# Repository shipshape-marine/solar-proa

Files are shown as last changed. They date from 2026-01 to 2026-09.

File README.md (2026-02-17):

# Solar Proa

## About

The solar proa is a novel boat design for carbon-neutral
small-scale tropical maritime transport, exploration, and tourism.
These boats combine traditional Southeast Asian and Polynesian
boat designs and rigs with solar power and modern materials.
More on solar proas is available at the website
[https://solarproa.org](https://solarproa.org).

This repo generates the website, including the parametric boat designs
and validation.

## How this repo works

The boat models specified in this repo are available at
[https://solarproa.org](https://solarproa.org). Changes in the boat
specs here are automatically reflected in the website.

The boat designs are programmed in Python.
Design-specific components live in `src/` while boat-independent analysis is provided by the [shipshape](https://github.com/shipshape-marine/shipshape) library. Features include:
- Main macro: The boat designs are generated by the _Solar Proa Design Generator_, [`SolarProa.FCMacro`](https://github.com/shipshape-marine/solar-proa/blob/main/SolarProa.FCMacro) using [FreeCAD](https://www.freecad.org/).
- Parameters: The boat is fully parameterized; the files [`constant/boat/rp*.json`](https://github.com/shipshape-marine/solar-proa/tree/main/constant/boat/) let you choose the numbers of solar panels and the size of all components. SolarProa-specific derived parameters are computed by [`src/parameter/compute.py`](https://github.com/shipshape-marine/solar-proa/blob/main/src/parameter/compute.py), loaded as a plugin by `shipshape.parameter`.
- Configurations: Moving parts such as rig, sails, rudders etc can be configured in the files [`constant/configuration/*.json`](https://github.com/shipshape-marine/solar-proa/tree/main/constant/configuration), for example [`closehaul.json`](https://github.com/shipshape-marine/solar-proa/blob/main/constant/configuration/closehaul.json).
- Mirroring: Solar proas have a transversal symmetry axis. Most components are described in file [`mirror.py`](https://github.com/shipshape-marine/solar-proa/blob/main/src/design/mirror.py) and automatically mirrored in the generated model.
- Rotation: Some parts such as the rigs and rudder can be rotated or moved independently (see file [`rotation.py`](https://github.com/shipshape-marine/solar-proa/blob/main/src/design/rotation.py)) in the configuration files.
- Structural validation: The structural validation lives in [`src/structural/`](https://github.com/shipshape-marine/solar-proa/tree/main/src/structural) and covers aka, mast, spine, and capsize analysis.
- Validation: The validation of the designs with respect to their mechanical, electrical and naval-engineering integrity is automated and the website reflects the validation results of the latest designs.

### Repo structure

```
src/
  parameter/compute.py   SolarProa-specific derived parameter calculations
  design/                FreeCAD geometry generation (central, mirror, rotation)
  color/                 Apply colors to FreeCAD models
  render/                Render images from FreeCAD
  step/                  Export to STEP format
  lines/                 Generate lines plan drawings
  buoyancy_design/       Position the boat at equilibrium in FreeCAD
  structural/            Structural validation (aka, mast, spine, capsize)
constant/
  boat/                  Boat specifications (rp2.json, rp4.json, ...)
  configuration/         Sail/rudder configurations (closehaul.json, ...)
  material/              Material properties
```

Analysis is provided by [shipshape](https://github.com/shipshape-marine/shipshape): parameter computation, mass analysis, buoyancy equilibrium, and GZ curves.

## Getting Started

0. Install `git` and `make`:
- **Linux**: `sudo apt install git make` (Ubuntu/Debian) or `sudo dnf install git make` (Fedora/RHEL)
- **macOS**: [Install Git](https://git-scm.com/install/mac), then run `xcode-select --install` for `make`
- **Windows**: [Git for Windows](https://git-scm.com/download/win) (includes Git Bash with `make`)

1. Clone this repository with `git clone git@github.com:shipshape-marine/solar-proa.git`

2. Install [FreeCAD](https://www.freecad.org/)

3. Start FreeCAD

4. Macro > Macros, then choose the file `SolarProa.FCMacro`

5. In the Solar Proa Design Generator, choose the boat (e.g. RP2) and configuration (e.g. Closehaul).

6. You should see the design (e.g. `rp2.closehaul.design`) in the FreeCAD view.

## Playing with the FreeCAD models

Change the boat specifications and rerun the macro:
- Change `constant/boat/rp2.json` to play with the number of solar panels, length of the boat etc.
- Change `constant/configuration/closehaul.json` to play with the sail settings, rudder position etc.
- Add or change boat features by editing `src/design/central.py`, `src/design/mirror.py`, or `src/design/rotation.py` and rerun the macro.

## Generating `FCStd` and `step` files from command line

To generate all designs (all boats with all configurations) just type
```
make
```
To generate an individual design, type
```
make design BOAT=rp2 CONFIG=closehaul
```
or
```
make step BOAT=rp2 CONFIG=closehaul
```
The generated files are placed in the folder `artifact`, for example:
```
artifact/rp2.closehaul.design.FCStd
artifact/rp2.closehaul.step.step
```

## Continuous Integration/Continuous Deployment (CICD)

The issue: when we have an idea for an improvement of the design, we
would need to redo all changes in all affected artifacts: the designs,
renderings, validations, and websites. CICD takes care of that by
automatically regenerating the artifacts. This is done locally, using
the `make` facility and on the github server using a workflow. The
workflow makes sure that the [solarproa.org](https://solarproa.org)
website has always the latest versions.

## Under the hood

Crucial for the CICD approach to CAD using FreeCAD is:
- FreeCAD's [macros](https://wiki.freecad.org/Macros) feature
- the ability to run FreeCAD headlessly (with GUI), using `freecadcmd` on Linux and using `--console` on Mac
- this [observation](https://forum.freecad.org/viewtopic.php?p=857226#p857226) by FreeCAD user [`jcsahnwaldt`](https://forum.freecad.org/memberlist.php?mode=viewprofile&u=85580&sid=a9af5bd37412a3771f25378b4c027a2c) to use GUI features in headless FreeCAD with `PySide.QtGui`

Some design decisions:
- Toolchain automation with [`make`](<https://en.wikipedia.org/wiki/Make_(software)>) using this [Makefile](https://github.com/shipshape-marine/solar-proa/blob/main/Makefile)
- Website generation using [Jekyll](<https://en.wikipedia.org/wiki/Jekyll_(software)>)
- JSON statistics generated by headless FreeCAD
- Rendering by headless FreeCAD using [`jcsahnwaldt`](https://github.com/jcsahnwaldt)'s observation

## Further development

Let's explore what output formats we can generate and what tools are available to get the most out of our FreeCAD designs. Any contributions are welcome.

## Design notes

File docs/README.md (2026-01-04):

# Install dependencies
bundle install

# Run Jekyll locally
bundle exec jekyll serve

# Open in browser
open http://localhost:4000/CAD/

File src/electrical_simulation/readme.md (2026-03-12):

# Installing PySpice and NgSpice for electonic circuit simulation

```bash
pip install pyspice

pyspice-post-installation --install-ngspice-dll

pyspice-post-installation --check-install
```

## Note:

Spice identifier name should not start with number or 'v'

- Number used to indicate array index for MPPT and solar panels
- v prefix added by ngspice removed for result output

<br>

# Intepreting Simulation Results

Decoding of s & p can be found using the regex key in [this file](../../constant/electrical/constants.json)

## Errors 

```json
    "error": {
        "keyword": "error",
        "array_count": 2,
        "data": [
            "(Array 0) Panel input current (18.2 A) exceeds max MPPT input current (5.0 A)",
            "(Array 1) Panel input current (18.2 A) exceeds max MPPT input current (5.0 A)"
        ]
    },
```

Errors are important issues that must be fixed before deploying the vessel. These errors if not fixed, is a hazzard in regards to fire and electrical safety.

## Warnings

```json
    "warning": {
        "keyword": "warning",
        "array_count": 1,
        "data": [
            "Battery array is being over-discharged. Motor 0 has been restricted to 129.04% instead of 1000.00% throttle level."
        ]
    },
```

Warnings are restrictions on the components due to limitations (i.e. Max battery discharge rate). They may cause issues such as pre-mature shutdown of the components as a safety features by the manufacturer. This is not an indicator that the vessel is unsafe but a simple warning that the components will not run as expected.

## Quick Summary 

```json
    "summary": {
        "keyword": "total",
        "array_count": 1,
        "data": [
            {
                "array_index": 0,
                "voltage": {
                    "total_mppt_output": 58.18912913606731,
                    "total_dc_bus_voltage": 58.18912813606731
                },
                "current": {
                    "total_mppt_output_current": 37.48509485,
                    "total_battery_input_current": -30.542116090829495
                }
            }
        ]
    },
```

A general overview of the system's status.

## MPPT (Array)

```json
    "mppt_result": {
        "keyword": "mppt",
        "array_count": 2,
        "data": [
            {
                "array_index": 0,
                "voltage": {
                    "mppt_output": 58.376555610317304
                },
                "current": {
                    "mppt_output": 18.742547425
                }
            },
            {
                "array_index": 1,
                "voltage": {
                    "mppt_output": 58.376555610317304
                },
                "current": {
                    "mppt_output": 18.742547425
                }
            }
        ]
    },
```

Depending on how many MPPT-Solar arrays are configured. RP2 will have 2 of it. Naming is from PySpice netlist but since MPPTs should not connect in series in any configurations due to safety issue, there will only ever be one voltage and current reading per array.

## Batteries
```json
    "battery_result": {
        "keyword": "battery",
        "array_count": 1,
        "data": [
            {
                "array_index": 0,
                "voltage": {
                    "p0_s1_battery_negative": 29.094548296975614,
                    "p0_s1_battery_positive": 58.494548296975616,
                    "p0_s0_battery_negative": -3.054211609082995e-05,
                    "p0_s0_battery_positive": 29.399969457883913
                },
                "current": {
                    "p0_s0_battery": -30.54211609082995,
                    "p0_s1_battery": -30.54211609082995
                }
            }
        ]
    },
```

Batteries only has 1 array count, but can be configured into series and parallel connection (Indicated by p & s). Can be decoded using the above regex key. Positive current: charging, Negative current: discharging.

## Solar Panel (Array)

```json
    "solar_result": {
        "keyword": "solar_array",
        "array_count": 2,
        "data": [
            {
                "array_index": 0,
                "voltage": {
                    "solar_array_output": 79.95455269744532
                },
                "current": {
                    "solar_array_output": 18.18966051116881
                }
            },
            {
                "array_index": 1,
                "voltage": {
                    "solar_array_output": 80.045449302557
                },
                "current": {
                    "solar_array_output": 18.210339488831718
                }
            }
        ]
    },
```

Following the MPPT_Solar array setup, each array corresponds to the array before. This section will be the input into their respective MPPT.

## Individual Solar Panels

```json
    "panel_result": {
        "keyword": "panel",
        "array_count": 2,
        "data": [
            {
                "array_index": 0,
                "voltage": {
                    "p1_s0_panel_positive": -9.100000000000001e-06,
                    "p1_1_panel_positive": 80.04550100000117,
                    "p1_1_panel_negative": -9.1e-06,
                    "p1_0_panel_positive": 9.1,
                    "p1_0_panel_negative": -9.1e-06,
                    "p0_s0_panel_positive": -9.100000000000001e-06,
                    "p0_1_panel_positive": 80.04550100000117,
                    "p0_1_panel_negative": -9.1e-06,
                    "p0_0_panel_positive": 9.1,
                    "p0_0_panel_negative": -9.1e-06
                },
                "current": {}
            },
            {
                "array_index": 1,
                "voltage": {
                    "p1_s0_panel_positive": -9.100000000000001e-06,
                    "p1_1_panel_positive": 80.136449302557,
                    "p1_1_panel_negative": -9.1e-06,
                    "p1_0_panel_positive": 9.1,
                    "p1_0_panel_negative": -9.1e-06,
                    "p0_s0_panel_positive": -9.100000000000001e-06,
                    "p0_1_panel_positive": 80.136449302557,
                    "p0_1_panel_negative": -9.1e-06,
                    "p0_0_panel_positive": 9.1,
                    "p0_0_panel_negative": -9.1e-06
                },
                "current": {}
            }
        ]
    },
```

Not a big concern. Factory cable is more than sufficient to carry the short connections between panels of up to 10 - 15A (10 - 12 AWG cables is more than sufficient).

## Load Balancer (Virtual)

```json
    "load_balancer": {
        "keyword": "balancing_load",
        "array_count": 1,
        "data": [
            {
                "array_index": 0,
                "voltage": {
                    "balancing_load": 58.18912713606731
                },
                "current": {
                    "balancing_load": 0.0
                }
            }
        ]
    },
```

Battery discharge limiter. Acts as a clamp to limit the battery to its specified discharge rate. Not a physical component.

## Loads

```json
    "load_result": {
        "keyword": "load",
        "array_count": 2,
        "data": [
            {
                "array_index": 0,
                "voltage": {
                    "load_torqeedo_cruise_4.0_positive": 56.8278085909551
                },
                "current": {
                    "load_torqeedo_cruise_4.0": 9.728971153497696
                },
                "motor_physics": {
                    "model_type": "BLDC",
                    "speed_rpm": 3245.7,
                    "efficiency": 0.89,
                    "power_mechanical_w": 1520.3,
                    "power_electrical_w": 1708.2,
                    "torque_nm": 4.47,
                    "is_stalled": false,
                    "propeller_load_factor": 1.0
                }
            },
            {
                "array_index": 1,
                "voltage": {
                    "load_torqeedo_cruise_6.0_positive": 56.147536482138094
                },
                "current": {
                    "load_torqeedo_cruise_6.0": 77.75618203729391
                },
                "motor_physics": {
                    "model_type": "linear",
                    "speed_rpm": null,
                    "efficiency": null,
                    "power_mechanical_w": null,
                    "power_electrical_w": 4365.2,
                    "torque_nm": null,
                    "is_stalled": null
                }
            }
        ]
    },
```

Loads are no longer stored within a single array (Similar to panels). Each load is its own index in the array. 

### Motor Physics Model (New)

When motor physics constants are configured in `components.json`, the simulation uses a BLDC motor model with optional propeller load coupling instead of the linear throttle-to-power conversion.

**Motor model features:**
- **Back-EMF**: Speed-dependent voltage that opposes motor current
- **Propeller equilibrium**: Finds operating point where motor torque = propeller torque (τ = Kp × ω²)
- **ESC current limiting**: Caps winding current at rated current (`total_power / nominal_voltage`)
- **Auto-derived propeller kp**: Calibrated so motor reaches rated current at full throttle
- **Efficiency calculation**: Mechanical power / electrical power
- **Non-linear power scaling**: Power scales with ~throttle³ due to propeller load curve

**Configuration** (in `constant/electrical/components.json`):

```json
"Torqeedo_Cruise_2.0": {
    "total_power": 2000,
    "nominal_voltage": 24.0,
    "motor_kv": 150,           // Motor velocity constant (RPM/V)
    "motor_resistance": 0.05,   // Winding resistance (ohms)
    "motor_no_load_current": 1.5, // No-load current (amps)
    "propeller_load_factor": 1.0  // 1.0=startup/bollard, 0.3-0.6=cruise equilibrium
}
```

The propeller load coefficient (`kp`) is auto-derived from motor specs so that the motor reaches its rated current at full throttle. To override with a custom value, add `"propeller_kp": <value>` to the config.

**ESC Current Limiting:**

The model simulates ESC current limiting: `max_current = total_power / nominal_voltage`. When the motor would exceed this, the ESC reduces voltage to hold the limit. Key behaviors when current-limited:
- Motor torque is constant (capped by current limit)
- Equilibrium speed is fixed regardless of throttle
- Power draw plateaus — increasing throttle has no further effect
- The `is_current_limited` output field indicates this condition

**Propeller Load Factor:**

The `propeller_load_factor` parameter (0.0–1.0, default 1.0) scales the propeller load coefficient `propeller_kp` to simulate different operating conditions:

| Value | Condition | Description |
|---|---|---|
| 1.0 | Startup / bollard pull | Boat stationary, propeller pushes against still water. Maximum power draw. |
| 0.5 | Moderate cruise | Water flowing through propeller reduces effective load by ~50%. |
| 0.3 | High-speed cruise | Propeller advancing rapidly, low slip, minimal loading. |
| 0.0 | Free-spinning | No propeller load (theoretical boundary). |

At startup (load_factor=1.0), power draw is **higher** than at cruise equilibrium because the propeller faces maximum water resistance. As the boat accelerates and water flows into the propeller, the effective load decreases.

You can estimate the factor from manufacturer power-at-speed data: if the motor draws 4kW at bollard pull but only 1.5kW at cruise speed, use `propeller_load_factor ≈ 0.375`.

The parameter can be overridden at runtime via `--propeller-load-factor` CLI argument, or set per-segment in voyage configurations.

**Backward compatibility:** If motor physics constants are not provided, the simulation falls back to the original linear model where `power = throttle × total_power`.

**Motor physics output fields:**
- `model_type`: "BLDC" for physics model, "linear" for fallback
- `speed_rpm`: Motor speed in RPM (null for linear model)
- `efficiency`: Motor efficiency 0-1 (null for linear model)
- `power_mechanical_w`: Mechanical power output (null for linear model)
- `power_electrical_w`: Electrical power consumption
- `torque_nm`: Motor torque in N·m (null for linear model)
- `is_stalled`: True if motor is in stall condition
- `is_current_limited`: True if ESC is limiting winding current
- `propeller_load_factor`: Load factor used (1.0=startup, <1.0=cruise)

Note: Due to limitations in PySpice simulation of a current limiter, if > 1 load is connected and in total is drawing > 200% of the bus output, the current of the motor may be negative (Indicating the load is a power source).

## Load (Array)

```json
    "l_array_result": {
        "keyword": "l_array",
        "array_count": 1,
        "data": [
            {
                "array_index": 0,
                "voltage": {
                    "l_array_positive": 57.508856026659025
                },
                "current": {}
            }
        ]
    }
```

New: placeholder section for the implemented load array.

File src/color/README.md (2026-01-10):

# Color Module

The color module applies material-based color schemes to FreeCAD designs. Colors, transparency, and display modes are defined in JSON files and applied based on material annotations in object labels.

## Overview

**Pipeline**: `design.FCStd` → `color module` → `color.FCStd` → `render module` → `PNG images`

The color module is a separate processing step that:
1. Reads a color scheme from JSON
2. Applies colors, transparency, and display modes to objects based on their materials
3. Saves a colored version of the design (`.color.FCStd`)
4. Generates a JSON artifact with statistics

## Usage

### Apply Colors to a Design

```bash
# Apply default color scheme
make color BOAT=rp2 CONFIGURATION=closehaul

# Apply specific color scheme
make color BOAT=rp2 CONFIGURATION=closehaul COLOR_SCHEME=wiring_view

# Apply colors to all existing designs
make color-all

# Apply specific scheme to all designs
make color-all COLOR_SCHEME=proa
```

### Generated Files

For `rp2.closehaul` with `proa` color scheme:
- `artifacts/rp2.closehaul.color.FCStd` - Colored FreeCAD design
- `artifacts/rp2.closehaul.color.json` - Statistics artifact

## Color Scheme Format

Color schemes are defined in `constants/colors/*.json`:

```json
{
  "scheme_name": "Proa Standard Colors",
  "description": "Default color scheme for solar proa visualizations",
  "version": "1.0",
  "materials": {
    "aluminum": {
      "color": [0.75, 0.75, 0.78],
      "transparency": 0,
      "display_mode": "Shaded",
      "description": "Structural aluminum tubes and profiles"
    },
    "plywood": {
      "color": [0.76, 0.60, 0.42],
      "transparency": 0,
      "display_mode": "Shaded",
      "description": "Marine plywood decking and structure"
    }
  }
}
```

### Color Scheme Properties

- **color**: RGB values from 0.0 to 1.0
- **transparency**: Integer from 0 (opaque) to 100 (fully transparent)
- **display_mode**: FreeCAD display mode (e.g., "Shaded", "Wireframe", "Flat Lines")

## Material Detection

The color module extracts material names from object labels using two formats:

### Format 1: Parentheses (legacy)
```
"Aka_0 (aluminum)" → material: "aluminum"
"Stanchion_2 (steel)" → material: "steel"
```

### Format 2: Double Underscore (preferred)
```
"Deck__plywood_001" → material: "plywood"
"Hull__marine_plywood" → material: "marine_plywood"
```

Both formats are case-insensitive and trailing numbers are stripped.

## Available Color Schemes

### `proa.json` (Default)
Standard color scheme for regular visualization. All materials opaque, realistic colors.

### `wiring_view.json` (Specialized)
Transparent hull view for showing electrical systems:
- Structure (aluminum, plywood): 80% transparent
- Hull exterior: 90% transparent
- Electrical components (wires, batteries, solar panels): Opaque with high-contrast colors

## Creating Custom Color Schemes

1. Create a new JSON file in `constants/colors/`
2. Define materials used in your designs
3. Set appropriate color, transparency, and display mode
4. Use it: `make color COLOR_SCHEME=your_scheme`

### Example: High Contrast Scheme

```json
{
  "scheme_name": "High Contrast",
  "description": "High contrast colors for presentations",
  "version": "1.0",
  "materials": {
    "aluminum": {
      "color": [0.2, 0.2, 0.8],
      "transparency": 0,
      "display_mode": "Shaded"
    },
    "plywood": {
      "color": [0.8, 0.5, 0.1],
      "transparency": 0,
      "display_mode": "Shaded"
    }
  }
}
```

## Platform Differences

### Linux
- Uses `freecad-python` in headless mode
- Colors applied via `color.py` script
- Fast and reliable

### macOS
- Requires GUI mode to persist ViewObject properties
- Uses `color_mac.sh` wrapper script
- Opens FreeCAD, applies colors, saves, quits
- Takes longer but produces identical results

## Integration with Build Pipeline

The color module is integrated into the Makefile dependency chain:

```
parameters.json
    ↓
design.FCStd
    ↓
color.FCStd  ← color scheme JSON
    ↓
render PNGs
```

Renders automatically depend on colored designs. If you run `make render`, it will:
1. Generate parameters (if needed)
2. Generate design (if needed)
3. Apply colors (if needed)
4. Render images

## Statistics Artifact

The `.color.json` artifact contains:

```json
{
  "validator": "color",
  "input_design": "artifacts/rp2.closehaul.design.FCStd",
  "output_design": "artifacts/rp2.closehaul.color.FCStd",
  "color_scheme_file": "constants/colors/proa.json",
  "color_scheme_name": "Proa Standard Colors",
  "statistics": {
    "total_objects": 150,
    "colored_objects": 142,
    "by_material": {
      "aluminum": 45,
      "plywood": 38,
      "steel": 29,
      "solar_panel": 18,
      "canvas": 12
    }
  }
}
```

## Troubleshooting

### No colors appear in renders

Check:
1. Does the object label include material? (e.g., "Aka_0 (aluminum)")
2. Is the material defined in the color scheme JSON?
3. Does the colored FCStd exist? (`artifacts/*.color.FCStd`)
4. Are you rendering the `.color.FCStd` file (not `.design.FCStd`)?

### Some objects not colored

Check the statistics in the `.color.json` artifact to see which materials were found and colored. Objects without material annotations or with undefined materials won't be colored.

### macOS color application hangs

The `color_mac.sh` script has a 30-second timeout. If it hangs:
1. Check if FreeCAD is installed at the expected path
2. Try running FreeCAD manually to verify it works
3. Check for FreeCAD processes that didn't exit cleanly

## Future Enhancements

Potential future features:
- Material-specific transparency for "exploded" views
- Animation support for rotating/transparency transitions
- Color validation (warn if materials in design aren't in scheme)
- Color scheme inheritance (extend base schemes)
- Per-object color overrides for special highlighting

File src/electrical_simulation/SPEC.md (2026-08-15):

# Electrical Simulation Module (`src/electrical_simulation`)

## Purpose

SPICE-based electrical circuit simulation of the solar proa's power system. Models solar panels, MPPT charge controllers, batteries, and electric motor loads to analyse power flow, validate component sizing, and simulate voyage energy profiles.

## Status: Active Development

Core simulation pipeline is functional. See `todo.md` for planned fixes.

---

## Architecture

```
__main__.py              CLI entry point & orchestrator
├── circuit_constructor  Builds PySpice netlist from JSON config
├── pyspice_simulator    Executes NgSpice operating point analysis
├── parse_result         Extracts node voltages/branch currents → structured dict
├── result_checker       Validates results (Kirchhoff, component limits, motor physics)
├── result_saver         Serialises results to JSON
├── simulation_sweeper   Runs parameter sweeps (throttle, panel power)
├── simulation_over_time Multi-segment voyage simulation with SOC tracking
├── sweep_graph_generation Matplotlib graph output (PNG)
├── cable_sizing         Derives cable gauge from max-current simulation
└── components/
    ├── solar_panel_array  Solar panel PySpice model (series/parallel)
    ├── mppt               MPPT charge controller model
    ├── battery_array      Battery bank model (series/parallel, SOC)
    ├── load               Individual load with BLDC motor physics
    ├── load_array         Multi-load bus connection & current distribution
    ├── load_balancer      Virtual battery discharge limiter
    └── motor_model        BLDC motor physics (back-EMF, propeller coupling)
```

---

## Dependencies (Centralised Parameters)

All parameters are loaded at runtime from JSON — no hardcoded values.

| File | Purpose | Key Fields |
|---|---|---|
| `constant/electrical/{boat}_circuit_setup.json` | Circuit topology per boat | `mppt_panel` (arrays, count, panel/MPPT choice), `load` (choice, throttle), `battery` (choice, series, parallel, SOC) |
| `constant/electrical/electrical_components.json` | Component specifications | `MPPT` (voltage/current limits, efficiency), `Panel` (power, voltage), `Battery` (voltage, capacity, charge/discharge limits), `Load` (power, voltage, motor physics) |
| `constant/electrical/constants.json` | Simulation constants | `GROUNDING_RESISTANCE`, `WIRE_RESISTANCE`, `EPSILON`, `ARRAY_DECODER_PATTERN`, tolerance values |
| `constant/electrical/voyage_setup.json` | Voyage segments | `segments[]` (duration_minutes, throttle, solar_power, propeller_load_factor) |
| `constant/boat/{boat}.json` | Boat physical params | `panels_longitudinal`, `panels_transversal`, `panels_per_string` → derived `in_series`, `in_parallel` for panel arrays |

### Dependency Graph

```
constant/boat/{boat}.json ──────────────────┐
constant/electrical/{boat}_circuit_setup.json ├──→ circuit_constructor → pyspice_simulator
constant/electrical/electrical_components.json ┘           │
constant/electrical/constants.json ─────────────────────── ┤
constant/electrical/voyage_setup.json ──────────── simulation_over_time
```

---

## CLI Usage

```bash
python -m src.electrical_simulation \
  --circuit constant/electrical/rp2_circuit_setup.json \
  --constants constant/electrical/constants.json \
  --components constant/electrical/electrical_components.json \
  --boat rp2 \
  --boat-params constant/boat/rp2.json \
  --voyage constant/electrical/voyage_setup.json \
  --output artifact/rp2.electrical_simulation \
  --simulation-type all
```

### Simulation Types

| Type | Description | Output |
|---|---|---|
| `operating_point` | Single DC steady-state | `.operating_point.json` |
| `cable_sizing` | Max-current operating point for cable gauge | `.max_operating_point.json` |
| `sweep_throttle` | 0→100% throttle sweep (101 points) | `.sweep_throttle.*.png`, `.json` |
| `sweep_panel_power` | 100→1% panel power sweep (100 points) | `.sweep_panel_power.*.png`, `.json` |
| `voyage` | Multi-segment time simulation | `.voyage.*.png` |
| `all` | Run all of the above sequentially | All outputs |

### Makefile Integration

```makefile
make electrical-simulation BOAT=rp2 SIMULATION_TYPE=all
```

---

## Result Structure

Results are a nested dictionary with these top-level keys:

```
info            → metadata (name, date)
error           → critical violations (Kirchhoff's law, component limits)
warning         → operational restrictions (discharge limiting, ESC capping)
summary         → total MPPT output voltage/current, DC bus voltage
mppt_result     → per-array MPPT output voltage/current
battery_result  → per-cell voltage, charge/discharge current
solar_result    → per-array solar output voltage/current
panel_result    → per-panel voltage (usually not critical)
load_balancer   → virtual balancer voltage/current
load_result     → per-load voltage/current + motor_physics
l_array_result  → load array bus voltage
```

Each section follows: `{ keyword, array_count, data: [{ array_index, voltage: {}, current: {} }] }`

---

## Key Algorithms

### Motor Physics (BLDC Model)

When `motor_kv`, `motor_resistance` are specified in component config:
1. Compute back-EMF constant: `Ke = 1 / (motor_kv * 2π/60)`
2. Auto-derive propeller Kp so motor reaches rated current at full throttle
3. Solve propeller-motor equilibrium: motor torque = Kp_effective × ω²
4. ESC current limiting: cap winding current at `total_power / nominal_voltage`
5. Output: speed_rpm, efficiency, torque, power_mechanical, is_stalled, is_current_limited

Falls back to linear model (`power = throttle × total_power`) when physics constants absent.

### Voyage SOC Tracking

1. Simulate each segment at 1-minute intervals
2. Integrate battery current: `capacity += current × step_time`
3. Boundary handling: split time step at exact SOC=0 or SOC=1 boundary
4. Re-simulate with discharge/charge disabled for remaining interval

---

## Unit Testing Guidance

### Critical Invariants to Test

1. **Kirchhoff's Current Law**: `Σ MPPT_out - Σ battery_in - Σ load_current = 0` (within EPSILON)
2. **Power conservation**: Input solar power × efficiency ≈ output power + losses
3. **SOC bounds**: `0.0 ≤ SOC ≤ 1.0` at all voyage time steps
4. **Motor physics**: speed, torque, efficiency within physical bounds
5. **Current limiting**: load current ≤ battery max_discharge_current

### Suggested Test Structure

```
tests/
├── test_circuit_constructor.py    # Config loading, component resolution
├── test_motor_model.py            # BLDC equilibrium, current limiting, edge cases
├── test_result_checker.py         # Kirchhoff validation, warning generation
├── test_simulation_sweeper.py     # Sweep produces expected point count
├── test_voyage.py                 # SOC boundary splitting, segment transitions
└── test_cable_sizing.py           # Current → gauge mapping
```

### Test Fixtures

- Use `constant/electrical/rp2_circuit_setup.json` as reference config
- Mock NgSpice for unit tests (test circuit_constructor independently)
- Use known-good result JSON as regression fixtures

---

## Related Modules

| Module | Relationship |
|---|---|
| `src/electrical_drawing` | Generates schematics of the same circuits (visual verification) |
| `src/power_cables` | Generates 3D cable geometry using same panel layout params |
| `src/parameter` | Computes derived parameters from boat JSON (upstream) |
| `src/design` | Generates FreeCAD geometry (upstream of power_cables) |

---

## Planned Work

- [ ] Multiple voyage configurations per boat
- [ ] Fix load current distribution: restrict total bus current first, then distribute proportionally
- [ ] Cable sizing implementation (currently stub)

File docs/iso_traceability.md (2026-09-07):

---
layout: default
title: Roti Proa II - ISO 12215 Traceability
---

[← Back to Structural Safety Report]({{ '/validation_rp2.html' | relative_url }})

---

## Purpose

This page maps RP2's existing structural safety factors (computed by the analytical
beam-theory suite in `src/structural/`) against the BS EN ISO 12215 small-craft
standard series, and reports where new ISO-anchored checks agree, disagree, or
cannot yet be computed for this vessel's asymmetric proa layout.

Full clause/table citations are recorded in
[`constant/standards/iso12215.json`](https://github.com/shipshape-marine/solar-proa/blob/main/constant/standards/iso12215.json)
in the repository. Per copyright terms, the ISO/BSI source PDFs themselves are held
locally by the design team and are not redistributed through this repository or site
— only bibliographic citations (standard, edition, clause/table number) are recorded.

Numbers on this page were computed by running `make validate-structure BOAT=rp2
CONFIGURATION=beaching`, which uses RP2's real modeled mass/geometry — they are
reproducible from the repository, not illustrative placeholders.

---

## The multihull gap is largely resolved

RP2's design team previously flagged that ISO 12215-5 (design pressures) is written
for **monohulls**, while RP2 is an asymmetric proa (one main hull + one outrigger
float) — a mismatch with no obvious governing standard on hand.

**ISO 12215-7:2020** ("Determination of loads for multihulls and of their local
scantlings using ISO 12215-5") is, in fact, on file with the design team. It gives
global load cases (crossbeam torsion, longitudinal shock, rig-load combination) and
float-specific local pressures that ISO 12215-5 alone does not cover.

It is still not a perfect fit: **ISO 12215-7's worked formulas assume a symmetric
catamaran or trimaran** (two equal hulls, or one hull + two equal floats). RP2 has
only one, asymmetric outrigger. Where a Part 7 formula is applied below, the
adaptation used and its confidence level is stated explicitly — nothing is silently
forced onto the proa geometry.

---

## Cross-check summary

| # | Load case | Existing SF (vs. raw yield, required ≥2.0) | ISO-anchored cross-check | Status |
|---|---|---|---|---|
| 1 | Suspended ama (aka bending) | **3.27** | GLC5 (ISO 12215-7 §12.10) dynamic longitudinal-shock case on the same aka: **SF = 1.35** vs. ISO's own design stress | ⚠️ See below — different load case, much tighter margin |
| 2 | Aka point load (crew standing) | 5.74 | Not separately re-derived (static, non-ISO-specific load case) | — |
| 3 | One end supported (spine bending) | 16.50 | Not separately re-derived | — |
| 4 | **Mast wind loading (25 kn)** | ~~6.18~~ **3.09 (corrected)** | ISO 12215-10:2020 Table 5 formula itself | ✅ Bug fixed — see below |
| 5 | Diagonal braces (lateral) | 33.60 | Reviewed against ISO 12215-7 Table 12 aluminium design stress convention | ✅ Confirmed genuine margin, not a modeling artifact — see below |
| 6–8 | Wave slam (vertical/frontal/sideways) | 4.46 / 5.23 / 4.46 | ISO 12215-7 §9.4 float bottom pressure: **0.44×** the ad hoc model's dynamic pressure | ℹ️ Ad hoc model is more conservative — see below |
| 9 | Lifting sling | 6.16 | Not an ISO-covered load case (crane/rigging, not a small-craft design load) | — |
| 10 | Gunwale loads | 12.24 | Not separately re-derived | — |
| 11 | Ama lift wind speed | 22 kn | Informational, unchanged | — |
| — | **Aka-to-vaka joint** | *(not previously checked at all)* | ISO 12215-6 good practice + first-pass weld sizing: passes a web-area rule of thumb | ⚠️ Real gap confirmed — see below |
| — | **Aluminium alloy spec** | *(not finalized)* | ISO 12215-3 §4.7: extruded-profile family (6000-series) is the correct choice | ⚠️ Documentation gap confirmed — see below |

---

## 1. Mast wind loading: a real formula bug, now fixed (6.18 → 3.09)

`mast_analysis.py` computed wind force as `F = 0.72 × V² × A / 2`, citing ISO
12215-10 Clause 7.2, Table 5. Checking the ISO 12215-10:2020 source directly (Table
5, Note 3):

> *"the wind force is F_A = N × 0.5 × ρ × A × V² (N) where N=1.2 ... ρ=1.2 kg/m³
> ... hence F_A = 0.720 × A × V² (N)"*

The 0.72 coefficient **already includes** the ½ dynamic-pressure term (1.2 × 0.5 ×
1.2 = 0.72). The code's extra `/2` halved the applied wind force, which
approximately doubled the reported safety factor. This has been corrected —
`mast_analysis.py` now computes `F = 0.72 × V² × A` with no extra division.

**Result on the real design**: mast wind-loading safety factor moves from **6.18 →
3.09**. The mast still comfortably passes the required minimum of 2.0 — this is a
correction to the reported number, not a design deficiency.

---

## 2. Diagonal braces (33.60): confirmed genuine margin, not a boundary-condition artifact

The design team's original concern was that the diagonal braces' very high safety
factor (33.60) might be a "fixed-support artifact" — i.e. that `brace_analysis.py`'s
Euler buckling calculation assumed unrealistically rigid end conditions.

Checking the actual computation: the code uses **K = 1.0 (pinned-pinned)**, which is
the *most conservative* standard idealization for buckling (it gives the *lowest*
buckling capacity among common end-fixity assumptions — any real end fixity, K <
1.0, would only *increase* the buckling load and therefore *increase* the reported
safety factor further). So K=1.0 is not an overly-rigid assumption; if anything it
already understates the brace's true capacity.

The real driver of the 33.60 figure: the brace's actual compressive load under the
"boat on its side" load case (698.5 N) is simply small relative to its Euler
buckling capacity (23,468 N) for this slenderness (88.3). Checked against ISO
12215-7 Table 12's aluminium buckling design-stress convention as well, nothing in
the governing standard changes this conclusion. **The 33.60 figure is genuine
margin, not a modeling artifact.**

---

## 3. Aka bending: existing 3.27 covers a different (lighter) load case than ISO's own dynamic global load

`aka_analysis.py`'s 3.27 safety factor is for the **suspended ama** case: static
weight of the outrigger (1g), no dynamic amplification, compared against raw
aluminium yield strength (240 MPa) with a required SF of 2.0.

ISO 12215-7 §12.10 (GLC5 — longitudinal shock, e.g. hitting a floating object or a
steep wave) is a genuinely different, **dynamic** load case that the existing suite
does not check at all. Adapting it to RP2 (treating the single ama as the closest
available "trimaran float" analogue, the most defensible fit in Part 7 for this
geometry):

- Longitudinal shock force: **F_LT = min(5×m_LDC, 5×m_ama) = 2.01 kN** (≈0.5g
  deceleration per ISO's own note)
- Distributed evenly across the 4 akas: **503.5 N per aka**
- Resulting weak-axis bending stress at the vaka connection: **59.75 MPa**
- Compared to ISO's own allowable design stress for a welded 6061 closed-profile
  extrusion (σ_d = 0.7×σ_yw = **80.5 MPa**, per ISO 12215-5 Table 17/Annex B):
  **SF = 1.35**

An SF of 1.35 against ISO's *own* design stress (which already includes ISO's
built-in knockdown from yield) means this case is ISO-compliant but with far less
margin than the 3.27 figure suggests for a different loading direction. **This is
the most actionable finding on this page**: the aka has comfortable margin against
the static suspended-weight case, but only modest margin against a dynamic
longitudinal-shock case that nothing in the existing suite previously checked.

*(GLC1 — the diagonal torsional-moment case in a quartering sea — was deliberately
**not** carried through to a per-aka number. ISO 12215-7 Annex D's distribution
method assumes the torsional moment is reacted by crossbeams twisting between two
hulls of the same type; RP2 has only one outrigger, so there is no second hull for
the akas to react against in the way Annex D models. Per ISO 12215-7 §12.3.3, a
non-typical arrangement like this needs the "enhanced method" (FEM), not the
simplified method — this is flagged as an open item requiring dedicated engineering
analysis, not force-fit into a formula that doesn't apply.)*

---

## 4. Aka-to-vaka joint: confirmed real gap, but for a different reason than assumed

The original assumption was that ISO 12215-6 §6.3/7.2 would give bonding-width /
k_j-style coefficients for this joint, similar to FRP tabbing calculations.

**Checking the source directly: ISO 12215-6 Clause 7.2 "Bonding" is specific to
FRP/composite construction.** It does not apply to the aluminium aka-to-vaka
connection at all. For metal construction, ISO 12215-6 gives only qualitative
good-practice principles:

- §6.3.1/6.3.2: loads transmitted via stiff brackets, not landed on unsupported
  material
- §8.2: end connections must provide "adequate end fixity and effective
  transmission of the bending moment and shear force" — no formula given
- §8.7/8.8: welding per Annex C good practice, or riveting with concrete geometric
  rules (rivet diameter, spacing, edge distance) — but still no joint-capacity
  formula

**There is no closed-form ISO 12215-6 formula for a metal end-connection's load
capacity.** This module derives a first-pass minimum by engineering analogy to
Clause 6.3.4 (which addresses a different connection type — floating frames — but
states "weld or glue area shall generally not be less than the stiffener web
area"): the aka's web area (833 mm²) exceeds the area required to carry the
suspended-ama case's moment and shear at ISO's welded design stress (governing
requirement: 391.5 mm²) — so this rule-of-thumb passes, but **it is not a
certified joint design**, because no joint design exists yet. This remains the
right place to focus engineering effort once a real bracket/weld geometry is
proposed.

---

## 5. Wave slam pressure: ad hoc model is more conservative than the ISO estimate

`wave_slam.py` estimates ama slam pressure from an assumed 3 m/s impact velocity, a
hand-picked slam coefficient (Cp=1.5), and a 2.5× dynamic factor — none of the three
numbers are ISO-derived.

Using ISO 12215-7 §9.4 ("Design pressure for trimaran floats" — again treating the
single ama as the closest available float analogue) and ISO 12215-5 §8/§9 for the
base formula and k_DC/k_L/k_AR factors:

- ISO-anchored design pressure at the ama's slam-affected area: **5.5 kPa**
- Existing ad hoc dynamic pressure: **17.3 kPa**
- Ratio: **0.32×** — the existing model is roughly 3× more conservative

This is a reasonable outcome (the ad hoc model was deliberately chosen to be
conservative) and gives the design team a real ISO-anchored floor to compare future
tuning of the ad hoc model against, rather than an unmoored guess.

*Caveats on the ISO-anchored number: it uses this codebase's modeled structural
mass rather than full ISO loaded displacement (crew/payload/fuel excluded, so it
likely understates the true design pressure); a placeholder Design Category B
(unconfirmed); k_AR without a documented stiffener-span reduction for the ama
shell; and an assumed mid-length slam location. See
`iso_design_pressure.py` for the full list.*

---

## 6. Aluminium alloy: family choice confirmed correct, documentation still open

ISO 12215-3 §4.7 classifies aluminium into non-heat-treatable (Mg-based, typically
rolled sheet/plate) and heat-treatable (Si-based, typically extruded
sections/tubes/closed profiles) families. The aka, braces, mast and gunwale are all
extruded closed-profile sections — **the heat-treatable (6000-series) family is the
correct choice per §4.7.3**, consistent with the 6061-T6 placeholder already used in
`beam_mechanics.py`.

What is still genuinely open (per the design team, no alloy/temper has been
finalized yet): ISO 12215-3 §7.3 requires a material data sheet stating chemical
composition, grade, temper, minimum mechanical properties, and — critically —
**minimum/expected mechanical properties after welding**. This does not exist yet.
It is a documentation gap to close before certification, not evidence the current
design is undersized: ISO's own tabulated values for a representative alloy
(EN AW-6061 T5/T6 closed profile) are already used throughout this page's
cross-checks as a stand-in.

One consequence worth flagging: **whether the aka-to-vaka joint ends up welded or
mechanically fastened changes the applicable ISO design stress by ~1.8×** (81 MPa
welded vs. 147 MPa unwelded/riveted, per ISO 12215-5 Table 17). This is undetermined
today because no joint design exists yet (see §4 above) — it is one more reason
that joint design is the highest-value open item.

---

## Summary of open items

1. **Aka global dynamic loading (GLC5)** — SF 1.35 against ISO's own design
   stress. Worth a closer look; the static suspended-ama check (3.27) does not
   cover this load direction.
2. **Aka-to-vaka joint** — no design exists; a first-pass ISO-anchored rule of
   thumb passes, but this needs a real bracket/weld design once the joint geometry
   is decided.
3. **Aluminium alloy/temper** — needs to be finalized and documented per ISO
   12215-3 §7.3 (including post-weld properties), since it affects both the
   material design stress and the joint design above.
4. **GLC1 (quartering-sea torsion)** — order-of-magnitude bound computed (7.6 kNm),
   but not distributed to individual akas; ISO 12215-7 itself says this asymmetric
   arrangement needs FEM ("enhanced method"), not the simplified formula.
5. **Design Category** — not yet formally declared; Category B assumed as a
   placeholder throughout this page's ISO-anchored calculations and must be
   confirmed per ISO 12217 before certification.

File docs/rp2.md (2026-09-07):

---
layout: default
title: Roti Proa II - 9m Day Tourism Vessel
---

<div style="display: flex; align-items: center; gap: 2em; margin-bottom: 2em; flex-wrap: wrap;">
  <div style="flex: 1; min-width: 400px; max-width: 600px;">
    Roti Proa II Construction
    <p style="font-size: 0.9em; color: #666; margin-top: 0.5em; font-style: italic;">Main hull of Roti Proa II under construction by Kim Tuck Huat Pte Ltd, 5/2/2026, Johor Bahru, Malaysia</p>
  </div>
</div>

[← Back to Home]({{ '/' | relative_url }})

---

## Design

Roti Proa II is a 9m daysailer that combines the basic body plan of a
Pacific proa with a fiberglass, PVC, aluminium materials to achieve a
configurable and scalable vessel concept.

**[View Full Design Specs →]({{ '/design_rp2.html' | relative_url }})**

**Hull Construction:**
- Professional fiberglass construction by Singapore boat maker
- Optimized for electric propulsion efficiency
- Delivery scheduled mid-February 2026

**Solar-Electric System:**
- 8 x 500W solar panels (4kW total)
- 48V electrical system
- Sponsored 4kW electric motor
- Integrated battery management

**Sailing Rig:**
- Dual aluminum stay-less masts
- Traditional tanja-inspired rectangular sails
- Shunting configuration for tropical conditions
- Backup propulsion capability

**Outrigger (Ama):**
- Aluminum crossbeam (aka) construction
- PVC pipe float construction  
- Optimized solar panel mounting
- Enhanced stability for passenger comfort

---

## Stability & Buoyancy

The vessel's stability has been analyzed using automated buoyancy equilibrium and GZ curve calculations.

**[View Full Stability & Buoyancy Analysis →]({{ '/stability_rp2.html' | relative_url }})**

| Parameter | Value | Description |
|---|---|---|
| Draft | {{ site.data.rp2_beaching_buoyancy.equilibrium.z_offset_mm }} mm | Depth below waterline at equilibrium |
| Max righting arm | {{ site.data.rp2_beaching_gz.summary.max_gz_m | times: 100 | round: 0 }} cm | At {{ site.data.rp2_beaching_gz.summary.max_gz_angle_deg }}° heel |
| Capsize angle | {{ site.data.rp2_beaching_gz.summary.capsize_angle_deg }}° | Away from ama |
| Turtle angle | {{ site.data.rp2_beaching_gz.summary.turtle_angle_deg }}° | Towards ama |
| Roll period | {{ site.data.rp2_beaching_gz.natural_periods.roll_period_s }} s | Rough estimate |
| Pitch period | {{ site.data.rp2_beaching_gz.natural_periods.pitch_period_s }} s | Rough estimate |
| Heave period | {{ site.data.rp2_beaching_gz.natural_periods.heave_period_s }} s | Rough estimate |

---

## Structural Validation

The vessel's structural integrity has been validated under multiple load scenarios including static loads, wave impacts, wind forces, and crane operations. All tests pass with safety factors exceeding the required minimum of 2.0.

**[View Full Structural Safety Report →]({{ '/validation_rp2.html' | relative_url }})**
**[View ISO 12215 Traceability →]({{ '/iso_traceability.html' | relative_url }})**

| Test | Safety Factor | Result |
|---|---|---|
| Suspended ama (aka bending) | {{ site.data.rp2_beaching_validate_structure.tests[0].summary.strong_axis.safety_factor }} | {{ site.data.rp2_beaching_validate_structure.tests[0].summary.strong_axis.result }} |
| Aka point load (crew standing) | {{ site.data.rp2_beaching_validate_structure.tests[1].summary.safety_factor }} | {{ site.data.rp2_beaching_validate_structure.tests[1].summary.result }} |
| One end supported (spine bending) | {{ site.data.rp2_beaching_validate_structure.tests[2].summary.safety_factor }} | {{ site.data.rp2_beaching_validate_structure.tests[2].summary.result }} |
| Mast wind loading (25 knots) | {{ site.data.rp2_beaching_validate_structure.tests[3].summary.safety_factor }} | {{ site.data.rp2_beaching_validate_structure.tests[3].summary.result }} |
| Diagonal braces (lateral) | {{ site.data.rp2_beaching_validate_structure.tests[4].summary.min_safety_factor }} | {{ site.data.rp2_beaching_validate_structure.tests[4].summary.result }} |
| Wave slam (vertical) | {{ site.data.rp2_beaching_validate_structure.tests[5].summary.min_safety_factor }} | {{ site.data.rp2_beaching_validate_structure.tests[5].summary.result }} |
| Frontal wave slam | {{ site.data.rp2_beaching_validate_structure.tests[6].summary.min_safety_factor }} | {{ site.data.rp2_beaching_validate_structure.tests[6].summary.result }} |
| Sideways wave slam | {{ site.data.rp2_beaching_validate_structure.tests[7].summary.min_safety_factor }} | {{ site.data.rp2_beaching_validate_structure.tests[7].summary.result }} |
| Lifting sling (crane) | {{ site.data.rp2_beaching_validate_structure.tests[8].summary.min_safety_factor }} | {{ site.data.rp2_beaching_validate_structure.tests[8].summary.result }} |
| Gunwale loads | {{ site.data.rp2_beaching_validate_structure.tests[9].summary.min_safety_factor }} | {{ site.data.rp2_beaching_validate_structure.tests[9].summary.result }} |
| Ama lift wind speed | {{ site.data.rp2_beaching_validate_structure.tests[10].summary.ama_lift_windspeed_knots }} knots | INFO |

---

## Electrical Simulation

The electrical system is modelled as a solar panel–MPPT–battery–motor DC circuit. The simulation computes the steady-state operating point, sweeps throttle and solar power levels to map system limits, and runs a multi-segment voyage profile to evaluate battery endurance and discharge constraints under realistic conditions.

**[View Full Electrical Setup & Simulation Result →]({{ '/electrical_rp2.html' | relative_url }})**

## Project Status

**Current Phase:** Under Construction

**Completed:**
- ✅ Detailed CAD design and optimization
- ✅ Hull order placed with boat maker
- ✅ Outrigger structure in progress
- ✅ Electrical system design
- ✅ Component procurement

**Next Steps:**
- Hull delivery (February 2026)
- Final assembly (March-April 2026)
- Sea trials (May-June 2026)
- Commercial validation with partners (Q3 2026)

---

[← Back to Home]({{ '/' | relative_url }}) | [View RP1 →]({{ '/rp1.html' | relative_url }}) | [View RP3 →]({{ '/rp3.html' | relative_url }})

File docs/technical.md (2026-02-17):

---
layout: default
title: Under the Hood - Technical Details
---

# Under the Hood

How the Solar Proa CAD system works.

[← Back to Home]({{ '/' | relative_url }})

---

## Parametric Design

All vessel designs are created using **parametric CAD modeling** - the geometry is defined by parameters (dimensions, angles, positions) rather than fixed shapes. This means:

- **Change one parameter, update the entire model** - Adjusting the hull length automatically scales masts, crossbeams, and rigging
- **Multiple configurations from one source** - The same base model generates beaching, close-haul, broad reach, and other sailing configurations
- **Design transparency** - Every dimension is traceable to a parameter value

The system uses [FreeCAD](https://www.freecad.org/) (open-source CAD) with Python scripts that read parameter files, build the 3D geometry, and export renders and CAD files.

---

## Build Pipeline

The build process transforms parameter files into website-ready outputs through a series of stages:

<div style="text-align: center; margin: 2em 0;">
  Build Pipeline Dependency Graph
  <p style="color: #666; font-size: 0.9em; margin-top: 0.5em;">Dependency graph auto-generated from Makefile</p>
</div>

**Stage descriptions:**

| Stage | Input | Output | Description |
|---|---|---|---|
| **parameter** | Boat JSON + Configuration JSON | Merged parameters | Combines boat dimensions with sail configuration (shipshape + project plugin) |
| **design** | Parameters | FreeCAD model (.FCStd) | Builds the 3D geometry from parameters |
| **mass** | Design (FreeCAD) | Mass properties JSON | Calculates volumes, masses, and buoyancy (shipshape) |
| **color** | Design (FreeCAD) | Colored design | Applies materials and colors for rendering |
| **buoyancy** | Design (FreeCAD), Mass properties | Buoyancy properties | Finds equilibrium pose using Newton-Raphson iteration (shipshape) |
| **gz** | Design (FreeCAD), Buoyancy | GZ curve JSON + PNG | Computes righting-arm curve over heel angles (shipshape) |
| **render** | Colored design (FreeCAD) | PNG images | Generates isometric, top, front, right views |
| **step** | FreeCAD model | STEP file | Exports universal CAD format |
| **validate** | Parameters, Mass, GZ | Validation JSON | Structural validation: aka, mast, spine, capsize analysis |

---

## Configurations

Each sailing configuration is defined by a JSON file that specifies sail angles, rig rotations, and other dynamic parameters:

```
constant/configuration/
├── beaching.json      # Sails down, on shore
├── beamreach.json     # Cross-wind sailing
├── broadreach.json    # Downwind sailing
├── closehaul.json     # Upwind sailing
├── closehaulreefed.json  # Heavy weather
└── goosewing.json     # Running downwind
```

The build system generates all combinations of boats × configurations automatically.

**Current configurations:**

<div style="display: grid; grid-template-columns: repeat(auto-fit, minmax(200px, 1fr)); gap: 1em; margin: 1em 0;">
{% for config in site.data.configurations %}
  <div style="border: 1px solid #ddd; padding: 1em; border-radius: 4px;">
    <strong>{{ config.display_name }}</strong>
    <p style="font-size: 0.85em; color: #666; margin: 0.5em 0 0 0;">{{ config.description }}</p>
  </div>
{% endfor %}
</div>

---

## Automation

Every push to the main branch triggers a GitHub Actions workflow that:

1. **Builds all FreeCAD models** for each boat × configuration combination
2. **Generates renders** (PNG images from multiple camera angles)
3. **Exports STEP files** for CAD interchange
4. **Calculates mass properties** and validates buoyancy
5. **Builds the Jekyll site** with all generated assets
6. **Deploys to GitHub Pages** at [solarproa.org](https://solarproa.org)

This ensures the website always reflects the current state of the CAD models - renders, specifications, and downloads are never out of sync.

---

## Repository Structure

Design-specific code lives in this repo. Boat-independent analysis (parameter merging, mass, buoyancy, GZ curves) is provided by the [shipshape](https://github.com/shipshape-marine/shipshape) library. Structural validation lives in `src/structural/`.

```
solar-proa/
├── constant/
│   ├── boat/              # Boat parameter files (rp1.json, rp2.json, rp3.json)
│   ├── configuration/     # Sailing configurations
│   └── material/          # Material properties (density, color)
├── src/
│   ├── parameter/         # SolarProa-specific derived parameter calculations
│   ├── design/            # FreeCAD model builders (central, mirror, rotation)
│   ├── color/             # Material and color application
│   ├── render/            # Render generation
│   ├── step/              # STEP export
│   ├── lines/             # Lines plan generation
│   ├── structural/        # Structural validation (aka, mast, spine, capsize)
│   └── buoyancy_design/   # Equilibrium positioning in FreeCAD
├── artifact/              # Generated outputs (models, renders, data)
├── docs/                  # Jekyll website source
└── Makefile               # Build orchestration
```

---

## Tools & Technologies

- **[FreeCAD 1.0](https://www.freecad.org/)** - Open-source parametric CAD
- **Python 3** - Scripting and automation
- **[shipshape](https://github.com/shipshape-marine/shipshape)** - Boat-independent naval engineering library (parameter, mass, buoyancy, GZ)
- **GNU Make** - Build orchestration and dependency tracking
- **Jekyll** - Static site generation
- **GitHub Actions** - CI/CD pipeline
- **Graphviz** - Dependency graph visualization

---

## Open Source

The entire project is open source under the [Apache License 2.0](https://www.apache.org/licenses/LICENSE-2.0).

**GitHub Repository:** [github.com/shipshape-marine/solar-proa](https://github.com/shipshape-marine/solar-proa)

Contributions, feedback, and forks are welcome.

---

[← Back to Home]({{ '/' | relative_url }}) | [View RP1 →]({{ '/rp1.html' | relative_url }}) | [View RP2 →]({{ '/rp2.html' | relative_url }}) | [View RP3 →]({{ '/rp3.html' | relative_url }})

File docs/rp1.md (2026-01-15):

---
layout: default
title: Roti Proa I - 4.2m Prototype
---

<div style="display: flex; align-items: center; gap: 2em; margin-bottom: 2em; flex-wrap: wrap;">
  <div style="flex: 1; min-width: 300px;">
    <h1 style="margin: 0;">Roti Proa I</h1>
    <h2 style="margin-top: 0.5em; font-weight: 300;">4.2-Meter Proof-of-Concept Prototype</h2>
  </div>
  <div style="flex: 1; min-width: 300px; max-width: 500px;">
    Roti Proa I
  </div>
</div>

[← Back to Home]({{ '/' | relative_url }})

---

## Overview

**Status:** ✅ Completed and tested (December 2024 - June 2025)

Roti Proa I was our proof-of-concept prototype that validated the feasibility of combining traditional outrigger design with modern solar-electric propulsion in tropical waters. The 4.2-meter vessel successfully demonstrated the core principles that inform our larger commercial designs.

**Key Achievements:**
- **Sea trials validated** in Singapore waters near Changi
- **Top speed:** 6.5 knots (12 km/h) under electric power
- **Solar capacity:** 1kW peak (2 panels)
- **Propulsion:** 2kW electric outboard motor
- **Battery:** LiFePO₄ system
- **Sailing rig:** Dual independent sport rigs for experimental configuration

The prototype proved that solar proas are viable for tropical Southeast Asian waters and provided crucial data for scaling up to the 9-meter Roti Proa II design.

---

## Featured Publication

For a detailed account of the Roti Proa I development, testing, and lessons learned, read the full article published by the Changi Sailing Club in Singapore:

**[Roti Proa: An Experimental Wind and Solar Powered Boat](https://www.csc.org.sg/2025/07/11/roti-proa-an-experimental-wind-and-solar-powered-boat/)**

This comprehensive article covers:
- Design philosophy and traditional influences
- Construction process and material choices
- Sea trial results and performance data
- Lessons learned for future development
- Technical challenges and solutions

---

## Quick Specifications

| Specification | Value |
|---|---|
| Overall Length (LOA) | 4.2m |
| Beam | 2.5m |
| Solar Power | 1kW peak |
| Motor Power | 2kW electric outboard |
| Battery Type | LiFePO₄ |
| Top Speed | 6.5 knots |
| Crew | 1-2 persons |
| Status | Testing completed June 2025 |

---

## 3D Renders

*Automatically generated from parametric CAD models*

{% assign render_files = site.static_files | where_exp: "file", "file.path contains 'renders'" | where_exp: "file", "file.path contains 'rp1'" | where_exp: "file", "file.extname == '.png'" %}

{% assign rp1_configs = "beaching,beamreach,broadreach,closehaul,closehaulreefed,goosewing" | split: "," %}

{% for config in rp1_configs %}
  <h3>{{ config | capitalize | replace: "beamreach", "Beam Reach" | replace: "broadreach", "Broad Reach" | replace: "closehaul", "Close Haul" | replace: "closehaulreefed", "Close Haul Reefed" | replace: "goosewing", "Goose Wing" }}</h3>
  
  <div style="display: grid; grid-template-columns: repeat(auto-fit, minmax(300px, 1fr)); gap: 1em; margin: 2em 0;">
  {% assign config_files = render_files | where_exp: "file", "file.basename contains config" | sort: "basename" %}
  {% for file in config_files %}
    <div>
      {{ file.basename }}
      <p style="text-align: center; font-size: 0.9em; color: #666; margin-top: 0.5em;">
        {{ file.basename | remove: "rp1." | remove: config | remove: ".render." | remove: "_" | replace: "front", "Back View" | replace: "isometric", "Isometric View" | replace: "right", "Right View" | replace: "top", "Top View" }}
      </p>
    </div>
  {% endfor %}
  </div>
{% endfor %}

---

## Legacy & Impact

Roti Proa I's successful trials provided the confidence and empirical data needed to pursue commercial-scale development. The prototype demonstrated that:

✅ Solar-electric propulsion is viable in tropical waters  
✅ Traditional outrigger designs adapt well to modern electric systems  
✅ Shunting proas can effectively integrate solar panels  
✅ The combination creates a compelling eco-tourism experience

These insights directly informed the design of Roti Proa II and validate our approach for the 13-meter Roti Proa III.

---

## Funding & Support

Roti Proa I was funded through:
- **Maybank Green Fund:** S$5,000 (via NUS Office of Student Affairs)
- **Private donations and sponsorships:** S$7,000
- **Total project cost:** S$12,000

---

## From Prototype to Product

The success of Roti Proa I demonstrates that our vision is technically sound. Now, with Roti Proa II under construction, we're taking the next step toward commercial viability—a vessel designed not just to prove a concept, but to serve real eco-tourism operations in tropical Southeast Asia.

**Read the full story:** [Changi Sailing Club Article →](https://www.csc.org.sg/2025/07/11/roti-proa-an-experimental-wind-and-solar-powered-boat/)

---

## Download CAD Models

Access CAD models for all sail configurations in FreeCAD (.FCStd) and STEP (.step) formats.
These files include the complete 3D geometry and can be modified for your specific requirements.

<div style="display: grid; grid-template-columns: repeat(auto-fit, minmax(280px, 1fr)); gap: 1em; margin: 2em 0;">
{% for config in site.data.rp1_downloads.configurations %}
  <div style="padding: 1em; border: 1px solid #ddd; border-radius: 4px;">
    <div style="font-weight: bold; margin-bottom: 0.5em; text-transform: capitalize;">
      {{ config.name | replace: "_", " " }}
    </div>
    {% if config.description %}
    <div style="font-size: 0.85em; color: #666; margin-bottom: 0.75em;">
      {{ config.description }}
    </div>
    {% endif %}
    <div style="display: flex; gap: 0.5em; flex-wrap: wrap;">
      <a href="{{ '/downloads/' | append: config.filename | relative_url }}" style="background: #28a745; color: white; padding: 0.4em 0.8em; border-radius: 4px; text-decoration: none; font-size: 0.9em;">
        📐 FreeCAD
      </a>
      {% if config.step_filename %}
      <a href="{{ '/downloads/' | append: config.step_filename | relative_url }}" style="background: #007bff; color: white; padding: 0.4em 0.8em; border-radius: 4px; text-decoration: none; font-size: 0.9em;">
        📦 STEP
      </a>
      {% endif %}
    </div>
  </div>
{% endfor %}
</div>

**Formats:**
- **FreeCAD (.FCStd):** Parametric model for [FreeCAD](https://www.freecad.org/) (free and open-source)
- **STEP (.step):** Universal CAD format compatible with most CAD software

**License:** Models are shared under [CC BY-SA 4.0](https://creativecommons.org/licenses/by-sa/4.0/) - free to use, modify, and share with attribution.

---

[← Back to Home]({{ '/' | relative_url }}) | [View RP2 →]({{ '/rp2.html' | relative_url }}) | [View RP3 →]({{ '/rp3.html' | relative_url }})

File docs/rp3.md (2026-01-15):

---
layout: default
title: Roti Proa III - 13m Multi-Day Vessel
---

<div style="display: flex; align-items: center; gap: 2em; margin-bottom: 2em; flex-wrap: wrap;">
  <div style="flex: 1; min-width: 300px;">
    <h1 style="margin: 0;">Roti Proa III</h1>
    <h2 style="margin-top: 0.5em; font-weight: 300;">13-Meter Solar-Electric Multi-Day Cruiser</h2>
  </div>
  <div style="flex: 1; min-width: 300px; max-width: 500px;">
    Roti Proa III
  </div>
</div>

[← Back to Home]({{ '/' | relative_url }})

---

## Vision: Scaling Up for Multi-Day Voyages

**Status:** 🔵 Design Phase | **Target:** Mid-2027 validation

Roti Proa III represents our vision for carbon-neutral multi-day coastal cruising in tropical Southeast Asia. Building on the lessons from RP1 (prototype) and RP2 (day tourism), RP3 will demonstrate that solar-electric propulsion can support extended voyages with overnight accommodation.

---

## Design Concept

Roti Proa III will be based on a **Dragon Boat DB22 hull** - a proven traditional design that offers:

- **Optimal length-to-beam ratio** for efficient electric propulsion
- **Proven seaworthiness** in Southeast Asian waters
- **Cultural significance** connecting to regional maritime heritage
- **Ample interior volume** for passenger accommodation
- **Established construction methods** for reliable building

### Why Dragon Boat Heritage?

Dragon boats have been used across Asia for over 2,000 years. The DB22 design represents centuries of refinement for tropical coastal waters - exactly our operational environment. By adapting this traditional hull to modern solar-electric propulsion, we honor maritime tradition while pioneering sustainable technology.

---

## Preliminary Specifications

| Specification | Estimated Value |
|---|---|
| Overall Length (LOA) | {{ site.data.rp3_closehaul_parameters.vaka_length }} mm |
| Beam (hull) | ~1.2m (traditional dragon boat proportions) |
| Beam (with outrigger) | {{ site.data.rp3_closehaul_parameters.beam }} mm |
| Capacity | 5-6 passengers + 2 crew |
| Solar Power | 6-8kW peak (estimated) |
| Motor Power | 5-6kW electric (estimated) |
| Cruising Speed | 8-10 knots |
| Range | Multi-day (100+ nautical miles) |
| Accommodation | Sleeping quarters for passengers |
| Galley | Electric cooking from solar excess |
| Water | Integrated desalination capability |

*Note: Specifications are preliminary and subject to refinement during detailed design phase*

---

## Key Innovations for Multi-Day Operation

**Extended Solar Capacity:**
- Larger solar array (6-8kW) for overnight battery charging
- Excess power for onboard cooking and water desalination
- Shore power compatibility for dock charging

**Accommodation Design:**
- Sleeping berths for 5-6 passengers
- Covered deck area for weather protection
- Galley with electric cooking facilities
- Freshwater storage and desalination
- Marine toilet facilities

**Enhanced Sailing Rig:**
- Scaled-up version of RP2's proven shunting design
- Increased sail area for long-distance passages
- Storm rig capability for safety

**Redundant Systems:**
- Dual motor configuration option
- Backup sailing capability
- Enhanced battery capacity for overnight operations

---

## Development Timeline

**2026 Q4:** Hull design finalization based on DB22 platform  
**2027 Q1-Q2:** Construction and system integration  
**2027 Q2-Q3:** Sea trials and certification  
**2027 Q4:** Commercial validation with strategic partners

---

## Target Applications

**Multi-Day Eco-Tourism:**
- Island-hopping expeditions (3-5 days)
- Marine wildlife observation cruises
- Cultural heritage coastal tours
- Educational sailing experiences
- Slow travel experiences connecting coastal communities

**Operational Advantages:**
- Zero fuel costs on multi-day voyages
- Quiet operation for wildlife observation
- Onboard cooking without diesel generators
- Fresh water generation from excess solar
- Premium eco-tourism positioning

---

## Design Philosophy

Roti Proa III embodies our core principle: **combining Southeast Asian maritime traditions with cutting-edge sustainable technology.**

The dragon boat hull represents 2,000+ years of Asian maritime engineering. Our contribution is adapting this proven design for the 21st century - replacing human paddlers with solar-electric propulsion while maintaining the hull's fundamental efficiency and seaworthiness.

This isn't just about technology transfer; it's about **cultural continuity** - showing that traditional designs remain relevant when paired with modern sustainability solutions.

---

## 3D Renders

*Automatically generated from parametric CAD models*

{% assign render_files = site.static_files | where_exp: "file", "file.path contains 'renders'" | where_exp: "file", "file.path contains 'rp3'" | where_exp: "file", "file.extname == '.png'" %}

{% assign rp3_configs = "beaching,beamreach,broadreach,closehaul,closehaulreefed,goosewing" | split: "," %}

{% for config in rp3_configs %}
  <h3>{{ config | capitalize | replace: "beamreach", "Beam Reach" | replace: "broadreach", "Broad Reach" | replace: "closehaul", "Close Haul" | replace: "closehaulreefed", "Close Haul Reefed" | replace: "goosewing", "Goose Wing" }}</h3>
  
  <div style="display: grid; grid-template-columns: repeat(auto-fit, minmax(300px, 1fr)); gap: 1em; margin: 2em 0;">
  {% assign config_files = render_files | where_exp: "file", "file.basename contains config" | sort: "basename" %}
  {% for file in config_files %}
    <div>
      {{ file.basename }}
      <p style="text-align: center; font-size: 0.9em; color: #666; margin-top: 0.5em;">
        {{ file.basename | remove: "rp3." | remove: config | remove: ".render." | remove: "_" | replace: "front", "Back View" | replace: "isometric", "Isometric View" | replace: "right", "Right View" | replace: "top", "Top View" }}
      </p>
    </div>
  {% endfor %}
  </div>
{% endfor %}

---

## Partnership Opportunities

RP3 development presents unique opportunities for strategic partners interested in:

- **Early-stage design collaboration** on multi-day eco-tourism vessels
- **Field testing participation** in 2027 validation phase
- **Market validation** for premium sustainable tourism experiences
- **Technology demonstration** for corporate sustainability initiatives

The 2027 timeline allows partners to influence design decisions while maintaining exposure to a novel market segment.

---

## From Prototype to Production

**RP1 (2025):** Proved the concept  
**RP2 (2026):** Validates commercial day-tourism operations  
**RP3 (2027):** Demonstrates multi-day voyage capability

This progression de-risks the technology while building toward our ultimate vision: a fleet of carbon-neutral vessels serving Southeast Asia's coastal eco-tourism market.

---

## Download CAD Models

Access CAD models for all sail configurations in FreeCAD (.FCStd) and STEP (.step) formats.
These files include the complete 3D geometry and can be modified for your specific requirements.

<div style="display: grid; grid-template-columns: repeat(auto-fit, minmax(280px, 1fr)); gap: 1em; margin: 2em 0;">
{% for config in site.data.rp3_downloads.configurations %}
  <div style="padding: 1em; border: 1px solid #ddd; border-radius: 4px;">
    <div style="font-weight: bold; margin-bottom: 0.5em; text-transform: capitalize;">
      {{ config.name | replace: "_", " " }}
    </div>
    {% if config.description %}
    <div style="font-size: 0.85em; color: #666; margin-bottom: 0.75em;">
      {{ config.description }}
    </div>
    {% endif %}
    <div style="display: flex; gap: 0.5em; flex-wrap: wrap;">
      <a href="{{ '/downloads/' | append: config.filename | relative_url }}" style="background: #28a745; color: white; padding: 0.4em 0.8em; border-radius: 4px; text-decoration: none; font-size: 0.9em;">
        📐 FreeCAD
      </a>
      {% if config.step_filename %}
      <a href="{{ '/downloads/' | append: config.step_filename | relative_url }}" style="background: #007bff; color: white; padding: 0.4em 0.8em; border-radius: 4px; text-decoration: none; font-size: 0.9em;">
        📦 STEP
      </a>
      {% endif %}
    </div>
  </div>
{% endfor %}
</div>

**Formats:**
- **FreeCAD (.FCStd):** Parametric model for [FreeCAD](https://www.freecad.org/) (free and open-source)
- **STEP (.step):** Universal CAD format compatible with most CAD software

**License:** Models are shared under [CC BY-SA 4.0](https://creativecommons.org/licenses/by-sa/4.0/) - free to use, modify, and share with attribution.

---

[← Back to Home]({{ '/' | relative_url }}) | [View RP1 →]({{ '/rp1.html' | relative_url }}) | [View RP2 →]({{ '/rp2.html' | relative_url }})

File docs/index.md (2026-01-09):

---
layout: default
title: Solar Proa - Wind-solar-powered Outrigger Boats
---

<div style="margin-bottom: 3em;">
  Roti Proa II - Solar-Electric Day Tourism Vessel
  <p style="text-align: center; color: #666; font-size: 0.9em; margin-top: 0.5em;">Roti Proa II - 9m solar-electric day tourism vessel</p>
</div>

## At a glance

Project _Solar Proa_ is developing wind-solar-powered hybrid vessels for carbon-neutral small-scale tropical maritime transport, exploration, and tourism.
Completion of our 9-meter minimal viable product _Roti Proa II_ is targeted for mid-2026 and strategic partnerships are available for commercial validation.

---

## The vision

Electric vehicle adoption across Asia has created new expectations for quiet, clean transportation - expectations that extend to maritime sector. We're bringing carbon-neutral propulsion to water transport, island-hopping, snorkeling, and diving tourism through vessels that combine:

- **Traditional Design** - Inspired by Austronesian outrigger proas and Indonesian sailing traditions
- **Modern Engineering** - Parametric CAD design, aluminum construction, efficient electric propulsion
- **Renewable Energy** - 4kW solar arrays plus sail propulsion for zero-emission operation

---

## Our Vessels

<div style="display: grid; grid-template-columns: repeat(auto-fit, minmax(250px, 1fr)); gap: 2em; margin: 2em 0;">
  <div style="border: 1px solid #ddd; padding: 1.5em; border-radius: 8px;">
    <h3>Roti Proa I</h3>
    <p><strong>Status:</strong> Completed & Tested (2025)</p>
    <p><strong>Size:</strong> 4.2m prototype</p>
    <p><strong>Achievement:</strong> Proof of concept validated in Singapore waters</p>
    <p><a href="{{ '/rp1.html' | relative_url }}">View Details & Renders →</a></p>
  </div>
  
  <div style="border: 1px solid #ddd; padding: 1.5em; border-radius: 8px; background: #f8f8f8;">
    <h3>Roti Proa II</h3>
    <p><strong>Status:</strong> Under Construction</p>
    <p><strong>Size:</strong> 9m day tourism vessel</p>
    <p><strong>Capacity:</strong> 4 passengers + 2 crew</p>
    <p><strong>Target:</strong> June 2026 completion</p>
    <p><a href="{{ '/rp2.html' | relative_url }}">View Details & Renders →</a></p>
  </div>
  
  <div style="border: 1px solid #ddd; padding: 1.5em; border-radius: 8px;">
    <h3>Roti Proa III</h3>
    <p><strong>Status:</strong> Design Phase</p>
    <p><strong>Size:</strong> 13m multi-day vessel</p>
    <p><strong>Capacity:</strong> 5-6 passengers</p>
    <p><strong>Target:</strong> 2027 validation</p>
    <p><a href="{{ '/rp3.html' | relative_url }}">View Details & Renders →</a></p>
  </div>
</div>

---

## Why Tropical Southeast Asia?

**Exceptional solar irradiation** makes the region ideally suited for sustainable maritime propulsion. Our designs optimize traditional outrigger configurations to maximize solar panel area while maintaining excellent sailing characteristics.

The shunting, single-outrigger layout provides:
- Ample space for solar arrays between hull and outrigger
- Sail positioning that avoids casting shadows on panels
- Superior stability and efficiency for safe hybrid propulsion

---

## Commercial Opportunities

**Eco-Tourism Applications:**
- Short-distance passenger transport
- Island-hopping and coastal exploration
- Snorkeling and diving expeditions  
- Educational sailing experiences
- Wildlife observation cruises

**Operational Advantages:**
- Zero fuel costs and carbon emissions
- Significantly lower maintenance than diesel
- Quiet operation enhancing wildlife experiences
- Regulatory advantages from green certifications

**Market Position:**
At 10 knots under motor power, Roti Proa II targets the contemplative pace of eco-tourism - where the journey itself is part of the value proposition.

---

## Technical Innovation

All vessel designs are created using **parametric CAD modeling in FreeCAD and Python**, enabling:

- Novel boat designs optimized for solar-wind-hybrid propulsion
- Continuous power and weather monitoring for accurate arrival time prediction
- Rapid design iteration and optimization, version control and design transparency
- Open-source accessibility for educational purposes

**[Explore the CAD Models →]({{ '/technical.html' | relative_url }})**

---

## Current Status & Timeline

**Q1 2026:** Main hull delivery (9m Roti Proa II)  
**Q2 2026:** Final assembly and sea trials  
**Q3 2026:** Commercial validation with strategic partners  
**2027+:** Pilot production and 13m vessel development

---

## Partnership Opportunities

We welcome strategic partners for:

- **Field testing collaboration** and operational feedback
- **Joint development** of eco-tourism protocols
- **Co-branding opportunities** for sustainability leadership
- **CSR alignment** through maritime innovation support

Partnership structures can be flexibly tailored to organizational priorities.

---

## Project Team

**Project Coordinator:** A/Prof Martin Henz, School of Computing, National University of Singapore

**Technical Advisors:** Naval architect, naval engineer, electrical engineer

**Support:** National University of Singapore, industry sponsors, private donors

---

## Contact

**Email:** henz@nus.edu.sg  
**Institution:** School of Computing, National University of Singapore

---

<div style="text-align: center; padding: 2em 0; color: #666; font-size: 0.9em;">
  <p><em>Combining Southeast Asian maritime traditions with modern sustainable technology</em></p>
  <p>This site and all CAD models are automatically built and deployed via GitHub Actions</p>
</div>

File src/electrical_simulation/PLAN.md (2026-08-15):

# Electrical Simulation Testing Plan

## Overview

Add a comprehensive test suite for the `electrical_simulation` module with:
- Unit tests (no NgSpice dependency)
- Integration tests (requires NgSpice)
- New Makefile targets: `make test-unit`, `make test-integration`, `make test`

---

## Component kwargs Reference

| Component | Required kwargs | Optional kwargs |
|---|---|---|
| `Battery_Array` | `battery_in_series`, `battery_in_parallel`, `battery_voltage` OR (`min_voltage` + `max_voltage`), `max_charge_current`, `max_discharge_current`, `capacity_ah` | `current_soc` (default 1.0), `choice` |
| `Solar_Array` | `in_series`, `in_parallel`, `voltage`, `calculated_power` | `solar_power` (used upstream to compute calculated_power) |
| `MPPT` | `max_input_voltage`, `max_input_current`, `max_output_voltage`, `max_output_current`, `efficiency` | — |
| `Load` | `load_name`, `nominal_voltage`, `total_power` | `throttle` (default 1.0), `motor_kv`, `motor_resistance`, `motor_no_load_current`, `propeller_kp`, `propeller_load_factor` |
| `Load_Balancer` | *(no kwargs)* | — |
| `Load_Array` | *(positional: circuit, components, constants, load_list)* | — |

## Component Descriptions

| Component | What it represents |
|---|---|
| `Solar_Array` | Voltage sources in series/parallel representing panels; provides current to MPPT input |
| `MPPT` | Current regulator converting solar input to DC bus output; limited by max_output_current; applies efficiency loss |
| `Battery_Array` | Voltage sources in series/parallel representing battery cells; provides DC bus reference voltage |
| `Load` | Behavioral current sink on DC bus; power demand from BLDC motor model or linear scaling (throttle x total_power) |
| `Load_Array` | Bus node connecting all loads; handles current distribution and discharge limiting |
| `Load_Balancer` | Behavioral current sink absorbing excess charge current when battery is full |

---

## Test Circuits

| Circuit Name | Panels | MPPTs | Batteries | Loads | Purpose |
|---|---|---|---|---|---|
| `charging_only_1panel` | 1x1 (1 array) | 1 | 1S1P | 0 | Pure charging, all solar to battery |
| `charging_only_2panel` | 1x1 (2 arrays) | 2 | 2S1P | 0 | Multi-array charging |
| `load_only_single` | 1x1 (solar_power=0) | 1 | 2S1P | 1 (linear) | Battery discharge only |
| `load_only_dual` | 1x1 (solar_power=0) | 1 | 2S1P | 2 (BLDC+linear) | Multi-load discharge, current distribution |
| `balanced_system` | 1x1 | 1 | 2S1P | 1 (BLDC) | Solar approx equals load, near equilibrium |
| `oversized_solar` | 1x1 (2 count) | 2 | 1S1P | 1 (linear, low throttle) | Excess solar triggers charge limiting |
| `high_load_system` | 1x1 | 1 | 1S1P (low discharge limit) | 1 (BLDC, high throttle) | Battery discharge limiting warning |

Test component values (simple round numbers for hand-calculation):
- **Test_Panel**: 100W, 20V
- **Test_MPPT**: max_output_current 10A, efficiency 0.9
- **Test_Battery**: 24V per cell, min 20V, max 28V, capacity 50Ah, charge/discharge limit 20A
- **Test_Battery_Low_Discharge**: same but max_discharge_current 5A
- **Test_Load_Linear**: 500W, 24V nominal (no motor physics)
- **Test_Load_BLDC**: 500W, 24V, motor_kv=100, motor_resistance=0.1, no_load_current=1.0

---

## Task Breakdown

### Task 1: Project test infrastructure setup

**Objective:** Set up pytest configuration, directory structure, conftest.py with shared fixtures, add pytest to requirements.txt.

**Implementation:**
- Create `tests/` directory at project root
- Create `tests/__init__.py` (empty)
- Create `tests/electrical_simulation/__init__.py` (empty)
- Create `pyproject.toml` with:
  ```toml
  [tool.pytest.ini_options]
  testpaths = ["tests"]
  markers = [
      "integration: requires NgSpice shared library (deselect with '-m not integration')",
  ]
  ```
- Create `tests/conftest.py` loading `constant/electrical/constants.json` as session-scoped fixture
- Create `tests/electrical_simulation/conftest.py` with fixtures loading test component specs and circuit configs from `tests/electrical_simulation/fixtures/`
- Add `pytest` and `pytest-mock` to `requirements.txt`

**Verify:** `pytest --collect-only` runs without errors.

---

### Task 2: Test fixture circuit configs

**Objective:** Create purpose-built JSON circuit configurations for testing.

**Implementation:**
- Create `tests/electrical_simulation/fixtures/` directory
- Create `test_components.json` with Test_Panel, Test_MPPT, Test_Battery, Test_Battery_Low_Discharge, Test_Load_Linear, Test_Load_BLDC
- Create circuit setup JSONs (one per test scenario from table above):
  - `charging_only_1panel.json`: 1 panel array (count=1), 1S1P battery, no loads
    - Expected: MPPT current = (100W x 0.9) / ~24V = 3.75A all into battery
  - `charging_only_2panel.json`: 1 panel array (count=2), 2S1P battery
    - Expected: ~2 x 3.75A charging
  - `load_only_single.json`: panel solar_power=0, 1 linear load at throttle=0.5
    - Expected: 250W / 48V = 5.2A from battery
  - `load_only_dual.json`: panel solar_power=0, 1 BLDC + 1 linear load
    - Expected: sum of both loads from battery
  - `balanced_system.json`: solar power approx equals load demand
    - Expected: battery current near 0
  - `oversized_solar.json`: 2 panel arrays, low-throttle load
    - Expected: load_balancer absorbs excess
  - `high_load_system.json`: 1 panel, battery with low discharge limit, high throttle
    - Expected: discharge warning
- Create `test_voyage_setup.json` (3 segments x 5 min):
  - Segment 1: throttle=0.8, solar=0 (discharge)
  - Segment 2: throttle=0, solar=1.0 (charge)
  - Segment 3: throttle=0.5, solar=0.5 (mixed)

**Verify:** All fixture files parse as valid JSON.

---

### Task 3: Unit tests — circuit constructor

**Objective:** Test circuit_constructor.py logic without NgSpice.

**File:** `tests/electrical_simulation/test_circuit_constructor.py`

**Tests:**
- `test_combine_config_resolves_panel_choice` — Verify panel choice merges component spec fields
- `test_combine_config_resolves_mppt_choice` — Verify MPPT choice resolves correctly
- `test_combine_config_resolves_battery_choice` — Verify battery choice resolves correctly
- `test_combine_config_resolves_load_choice` — Verify load choice resolves correctly
- `test_apply_boat_panel_config_overrides` — Verify in_series/in_parallel override from boat params
- `test_apply_boat_panel_config_noop_without_fields` — Verify no-op when boat_params lacks panel fields
- `test_modifications_throttle_single` — Verify throttle_setting modifies load throttle (single value)
- `test_modifications_throttle_list` — Verify throttle_setting as list assigns per-load
- `test_modifications_panel_power` — Verify panel_power_setting modifies calculated_power
- `test_modifications_soc` — Verify current_soc passed to battery
- `test_modifications_discharge_limit` — Verify max_discharge_current override
- `test_modifications_charge_limit` — Verify max_charge_current override
- `test_modifications_propeller_load_factor` — Verify propeller_load_factor passed to loads
- `test_component_object_keys` — Verify returned dict has battery_array, mppt, solar_array, load, l_array, load_balancer
- `test_error_on_voltage_mismatch` — Verify errors list populated on battery/MPPT mismatch

**Verify:** All pass with `pytest -m "not integration"`.

---

### Task 4: Unit tests — result checker

**Objective:** Test result_checker.py validation logic with synthetic data.

**File:** `tests/electrical_simulation/test_result_checker.py`

**Tests:**
- `test_kcl_balanced_no_error` — "Verify no KCL error when MPPT output equals battery input plus load current"
- `test_kcl_violated_generates_error` — "Verify KCL violation generates error when currents don't sum to zero"
- `test_overcharge_warning_when_balancer_active` — "Verify overcharge warning when load_balancer carries positive current"
- `test_overdischarge_warning_on_power_mismatch` — "Verify over-discharge warning when load receives less power than expected"
- `test_motor_physics_attached_for_bldc` — "Verify BLDC motor_physics dict attached to load result when motor model exists"
- `test_linear_model_fallback_attached` — "Verify linear model motor_physics attached when no motor model"

**Approach:** Build synthetic result dicts mimicking real structure. Mock component_object with `.get_motor_operating_point()`, `.power_rating()`, `.throttle_setting()`, `.get_efficiency()`, `.get_output_limit()`.

**Verify:** All pass without NgSpice.

---

### Task 5: Unit tests — parse_result and result_saver

**Objective:** Test result parsing and JSON serialization.

**Files:**
- `tests/electrical_simulation/test_parse_result.py`
- `tests/electrical_simulation/test_result_saver.py`

**Tests (parse_result):**
- `test_nodes_categorized_by_keyword` — "Verify node voltages placed in correct result section based on keyword match"
- `test_array_index_extraction` — "Verify array index correctly extracted from node name pattern arr{N}_"
- `test_battery_voltage_postprocess` — "Verify per-cell voltage computed as positive minus negative terminal"
- `test_unmatched_node_printed` — "Verify unmatched node names printed to stdout" (use capsys)
- `test_branch_current_categorization` — "Verify branch currents placed in correct section with v-prefix stripped"

**Tests (result_saver):**
- `test_saves_valid_json` — "Verify result dict saved as valid JSON with 4-space indent"
- `test_file_is_readable` — "Verify saved file can be loaded back and matches original"

**Approach:** Mock NgSpice analysis object with `.nodes` and `.branches` dicts. Each value has `.as_ndarray()` returning `np.array([float_value])`. Use `tmp_path` for file tests.

**Verify:** All pass without NgSpice.

---

### Task 6: Unit tests — simulation_sweeper logic

**Objective:** Test sweep iteration counts, parameter ranges, failure handling.

**File:** `tests/electrical_simulation/test_simulation_sweeper.py`

**Tests:**
- `test_throttle_sweep_101_iterations` — "Verify throttle sweep runs exactly 101 simulations from 0% to 100%"
- `test_throttle_sweep_sets_panel_power_zero` — "Verify throttle sweep fixes panel_power_setting=0 to isolate throttle effect"
- `test_panel_sweep_100_iterations` — "Verify panel power sweep runs 100 simulations from 100% down to 1%"
- `test_panel_sweep_sets_throttle_one` — "Verify panel sweep fixes throttle_setting=1.0 to isolate solar effect"
- `test_panel_sweep_stops_on_failure` — "Verify panel power sweep stops when simulation returns None analysis"
- `test_propeller_load_factor_passed_through` — "Verify propeller_load_factor override reaches modifications dict"
- `test_graph_called_with_correct_args` — "Verify generate_graph receives results list and correct x-axis"

**Approach:** Mock `build_circuit_from_json`, `begin_simulation`, and `generate_graph`. No NgSpice, no graph files.

**Verify:** Fast unit tests, all pass without NgSpice.

---

### Task 7: Unit tests — simulation_over_time (voyage) logic

**Objective:** Test voyage SOC tracking, boundary splitting, segment transitions.

**File:** `tests/electrical_simulation/test_voyage.py`

**Tests:**
- `test_soc_increases_during_charging` — "Verify SOC increases when battery input current is positive"
- `test_soc_decreases_during_discharge` — "Verify SOC decreases when battery input current is negative"
- `test_soc_clamped_at_one` — "Verify SOC does not exceed 1.0; step splits and max_charge_current set to 0"
- `test_soc_clamped_at_zero` — "Verify SOC does not go below 0.0; step splits and max_discharge_current set to 0"
- `test_boundary_split_time_calculation` — "Verify time-to-full/empty calculated correctly from current and remaining capacity"
- `test_multi_segment_order` — "Verify segments execute in order with correct throttle and solar settings"
- `test_abort_on_simulation_failure` — "Verify voyage stops and generates partial graph when analysis is None"
- `test_step_up_prev_duplicates_entry` — "Verify step-function plot data correctly duplicated at boundaries"

**Math verification:** Given capacity=100Amin, current=10A, time_to_full = (max - current) / current.

**Approach:** Mock `build_circuit_from_json` and `begin_simulation` to return controlled results with known battery currents.

**Verify:** All pass without NgSpice.

---

### Task 8: Integration tests — simple circuit operating points

**Objective:** Run real NgSpice simulations with test circuits, validate against hand-calculated values.

**File:** `tests/electrical_simulation/test_integration_circuits.py`

**Mark:** All tests with `@pytest.mark.integration`

**Shared helpers:**
```python
def assert_kcl(result, epsilon=1e-3):
    """Verify KCL: MPPT_out - battery_in - load_current = 0"""

def run_circuit(fixture_name, conftest_fixtures) -> dict:
    """Build and simulate a test circuit, return result dict."""
```

**Tests (each with descriptive docstring):**
- `test_charging_only_1panel`:
  > "Single panel charges battery with no load. Expected: MPPT output current approx (100W x 0.9) / ~24V = 3.75A. All current flows into battery."
- `test_charging_only_2panel`:
  > "Two independent panel arrays charge battery. Expected: Each MPPT approx 3.75A, total approx 7.5A into battery."
- `test_load_only_single`:
  > "Single linear load draws from battery with no solar. Expected: load current approx 250W / 48V = 5.2A from battery."
- `test_load_only_dual`:
  > "Two loads (BLDC + linear) share DC bus. Expected: total current = sum of individual demands."
- `test_balanced_system`:
  > "Solar input approximately equals load demand. Expected: battery current near zero."
- `test_oversized_solar`:
  > "Excess solar exceeds battery charge limit. Expected: load balancer absorbs excess, overcharge warning."
- `test_high_load_system`:
  > "Load demand exceeds battery discharge limit. Expected: load restricted, over-discharge warning."

**Tolerance:** 5% for current/power comparisons:
```python
expected_current = (panel_power * efficiency) / bus_voltage
actual_current = result["mppt_result"]["data"][0]["current"]["mppt_output"]
assert abs(actual_current - expected_current) / expected_current < 0.05
```

**Verify:** Requires NgSpice. Each test self-contained with clear docstrings.

---

### Task 9: Integration tests — sweep and voyage end-to-end

**Objective:** Run sweeps and voyage with test fixtures, validate physical invariants.

**File:** `tests/electrical_simulation/test_integration_sweep.py`

**Mark:** All with `@pytest.mark.integration`

**Tests:**
- `test_throttle_sweep_monotonic_power`:
  > "Sweep throttle 0-100% and verify power is monotonically non-decreasing."
- `test_throttle_sweep_zero_throttle_zero_load`:
  > "At throttle=0, load power should be approximately zero."
- `test_throttle_sweep_kcl_all_points`:
  > "Verify KCL holds at every point in the throttle sweep."
- `test_panel_sweep_decreasing_mppt_current`:
  > "As panel power decreases, MPPT output current should decrease."
- `test_voyage_soc_bounds`:
  > "Run 3-segment voyage, verify SOC stays within [0.0, 1.0] at all time steps."
- `test_voyage_discharge_segment`:
  > "During high-throttle/no-solar segment, SOC must decrease."
- `test_voyage_charge_segment`:
  > "During zero-throttle/full-solar segment, SOC must increase."

**Approach:** Use reduced sweep (11 points) or call loop logic directly for speed. Use `tmp_path` for outputs.

**Verify:** Requires NgSpice. Physical invariants hold across all points.

---

### Task 10: Add kwargs documentation to component source files

**Objective:** Add docstrings documenting required/optional kwargs to each component's `__init__`.

**Files to modify:**
- `src/electrical_simulation/components/battery_array.py` — Battery_Array.__init__
- `src/electrical_simulation/components/solar_panel_array.py` — Solar_Array.__init__
- `src/electrical_simulation/components/mppt.py` — MPPT.__init__
- `src/electrical_simulation/components/load.py` — Load.__init__
- `src/electrical_simulation/components/load_array.py` — Load_Array.__init__
- `src/electrical_simulation/components/load_balancer.py` — Load_Balancer.__init__

**Example (Battery_Array):**
```python
def __init__(self, circuit, components, constants=None, **kwargs):
    """
    Battery array component.

    Required kwargs:
        battery_in_series (int): Number of cells in series
        battery_in_parallel (int): Number of strings in parallel
        battery_voltage (float): Per-cell nominal voltage (V) — used if min/max not provided
        min_voltage (float): Per-cell min voltage (V) — used with max_voltage for SOC estimation
        max_voltage (float): Per-cell max voltage (V)
        max_charge_current (float): Max charge current per string (A)
        max_discharge_current (float): Max discharge current per string (A)
        capacity_ah (float): Per-string capacity (Ah) — used by voyage for SOC tracking

    Optional kwargs:
        current_soc (float): Current state of charge, 0.0-1.0 (default: 1.0)
        choice (str): Component name from electrical_components.json (resolved upstream)
    """
```

**Verify:** No behavioral change. Existing test_motor_model.py still passes.

---

### Task 11: Makefile targets and CI integration

**Objective:** Add make targets and optionally wire into CI.

**Add to Makefile:**
```makefile
# ==============================================================================
# TESTING
# ==============================================================================

.PHONY: test test-unit test-integration

test-unit:
	@echo "Running unit tests (no NgSpice required)..."
	@$(PYTHON) -m pytest tests/ -m "not integration" -v --tb=short
	@echo ""
	@echo "✓ Unit tests complete"

test-integration:
	@echo "Running integration tests (requires NgSpice)..."
	@$(PYTHON) -m pytest tests/ -m "integration" -v --tb=short
	@echo ""
	@echo "✓ Integration tests complete"

test:
	@echo "Running all tests..."
	@echo ""
	@$(MAKE) test-unit
	@echo ""
	@$(MAKE) test-integration
	@echo ""
	@echo "✓ All tests complete"
```

**Add to help target:**
```
@echo "  make test                   - Run all tests (unit first, then integration)"
@echo "  make test-unit              - Run unit tests only (no NgSpice needed)"
@echo "  make test-integration       - Run integration tests only (requires NgSpice)"
```

**Move existing test:** `src/electrical_simulation/components/test_motor_model.py` to `tests/electrical_simulation/test_motor_model.py` (update imports from relative to absolute).

**Optional CI step** in `.github/workflows/pages.yml` after "Install PySpice":
```yaml
- name: Run electrical simulation tests
  run: |
    make test
```

**Verify:** `make test-unit` works without NgSpice. `make test` shows unit results first, then integration.

---

## Validation Approach for Sweep/Voyage Tests

For simulations like sweep and voyage, use mathematical estimation:

1. **Power conservation:** Input solar power x efficiency = output power + losses
2. **KCL at every point:** Sum of currents at DC bus = 0 (within EPSILON)
3. **Monotonic relationships:** More throttle = more power (always)
4. **SOC integration:** capacity += current x time (exact math, verifiable)
5. **Boundary conditions:** SOC in [0, 1], current limited at boundaries

Tolerance of 5% accounts for wire resistances (~0.01 ohm) and grounding resistors (~1e-6 ohm) which introduce small deviations from ideal calculations.

---

## Execution Order

Tasks must be executed in sequence (1 through 11). Each builds on the previous:
- Task 1-2: Infrastructure and fixtures (no tests yet)
- Task 3-7: Unit tests (can run immediately, no NgSpice)
- Task 8-9: Integration tests (require NgSpice + fixtures from Task 2)
- Task 10: Documentation (no dependency)
- Task 11: Makefile wiring (depends on all tests existing)

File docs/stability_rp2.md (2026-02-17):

---
layout: default
title: Roti Proa II - Stability & Buoyancy Analysis
---

[← Back to Roti Proa II Overview]({{ '/rp2.html' | relative_url }})

---

## Buoyancy Analysis

<div style="display: grid; grid-template-columns: repeat(auto-fit, minmax(300px, 1fr)); gap: 1em; margin: 2em 0;">
  <div>
    Buoyancy equilibrium - front view
    <p style="text-align: center; font-size: 0.9em; color: #666; margin-top: 0.5em;">Front view at equilibrium</p>
  </div>
  <div>
    Buoyancy equilibrium - side view
    <p style="text-align: center; font-size: 0.9em; color: #666; margin-top: 0.5em;">Side view at equilibrium</p>
  </div>
</div>

The buoyancy equilibrium is computed using Newton's method, iteratively adjusting the roll/pitch/z-offset of the boat until the center and amount of buoyancy match the center and amount of mass. The analysis uses the beaching configuration (no sails, rudders lifted).

### Equilibrium Position

| Parameter | Value |
|---|---|
| Z-offset (draft) | {{ site.data.rp2_beaching_buoyancy.equilibrium.z_offset_mm }} mm |
| Pitch | {{ site.data.rp2_beaching_buoyancy.equilibrium.pitch_deg }}° |
| Roll | {{ site.data.rp2_beaching_buoyancy.equilibrium.roll_deg }}° |
| Iterations to converge | {{ site.data.rp2_beaching_buoyancy.iterations }} |

### Vaka (Main Hull)

| Parameter | Value |
|---|---|
| Submerged volume | {{ site.data.rp2_beaching_buoyancy.vaka.submerged_volume_liters }} liters |
| Total volume | {{ site.data.rp2_beaching_buoyancy.vaka.total_volume_liters }} liters |
| Submerged percentage | {{ site.data.rp2_beaching_buoyancy.vaka.submerged_percent }}% |
| Z position (world) | {{ site.data.rp2_beaching_buoyancy.vaka.z_world_mm }} mm |

### Ama (Outrigger Float)

| Parameter | Value |
|---|---|
| Submerged volume | {{ site.data.rp2_beaching_buoyancy.ama.submerged_volume_liters }} liters |
| Total volume | {{ site.data.rp2_beaching_buoyancy.ama.total_volume_liters }} liters |
| Submerged percentage | {{ site.data.rp2_beaching_buoyancy.ama.submerged_percent }}% |
| Z position (world) | {{ site.data.rp2_beaching_buoyancy.ama.z_world_mm }} mm |

### Centers of Mass and Buoyancy

| Point | X (mm) | Y (mm) | Z (mm) |
|---|---|---|---|
| Center of Gravity | {{ site.data.rp2_beaching_buoyancy.center_of_gravity_world.x }} | {{ site.data.rp2_beaching_buoyancy.center_of_gravity_world.y }} | {{ site.data.rp2_beaching_buoyancy.center_of_gravity_world.z }} |
| Center of Buoyancy | {{ site.data.rp2_beaching_buoyancy.center_of_buoyancy.x }} | {{ site.data.rp2_beaching_buoyancy.center_of_buoyancy.y }} | {{ site.data.rp2_beaching_buoyancy.center_of_buoyancy.z }} |

See [implementation](https://github.com/shipshape-marine/shipshape/blob/main/src/shipshape/buoyancy/__main__.py).

---

## Stability Analysis (GZ Curve)

The GZ curve (righting arm curve) shows how the boat's stability varies with heel angle. For each heel angle, we compute the equilibrium waterline (where buoyancy equals weight) and measure the horizontal distance between the center of buoyancy (CoB) and center of gravity (CoG). This distance—the righting arm GZ—multiplied by displacement gives the righting moment that returns the boat to equilibrium.

<div style="max-width: 800px; margin: 2em auto;">
  GZ Curve
</div>

### Asymmetric Stability Characteristics

As a proa with an outrigger (ama), this vessel has asymmetric stability:

**Towards ama (positive heel):** The ama provides substantial buoyancy leverage when submerged.

| Parameter | Value |
|---|---|
| Maximum righting arm | {{ site.data.rp2_beaching_gz.summary.max_gz_m | times: 100 | round: 0 }} cm |
| Angle of maximum GZ | {{ site.data.rp2_beaching_gz.summary.max_gz_angle_deg }}° |
| Turtle angle | {{ site.data.rp2_beaching_gz.summary.turtle_angle_deg }}° |

**Away from ama (negative heel):** Stability comes from the elevated ama's weight acting as counterweight.

| Parameter | Value |
|---|---|
| Capsize angle | {{ site.data.rp2_beaching_gz.summary.capsize_angle_deg }}° |
| Ama engagement angle | {{ site.data.rp2_beaching_gz.summary.ama_engagement_angle_deg }}° |
| Range of positive stability | {{ site.data.rp2_beaching_gz.summary.range_of_positive_stability_deg }}° |

### Operating Envelope

Traditionally, proas are sailed with the ama to windward. The wind force heels the boat away from the ama, lifting it (partially or even completely) out of the water to reduce drag ("flying the ama"). The operating envelope is typically -5° to -20° heel in that case, well within the stable region.

A _solar_ proa should be able to sail well also with the ama to leeward, to keep the sails from casting a shadow on the solar panels. At a heeling angle of around 4°, the ama will be fully submerged and cause maximum drag but still induce a significant righting moment until the turtle angle is reached.

---

## Natural Periods (Seakeeping)

The vessel's motion in waves is characterized by natural periods for roll, pitch, and heave. These are **rough estimates** using simplified empirical formulas; the standard linearized naval architecture formulas don't apply well to asymmetric proa hulls. Physical testing is recommended for accurate values.

| Motion | Period | Formula | Description |
|---|---|---|---|
| Roll | {{ site.data.rp2_beaching_gz.natural_periods.roll_period_s }} s | T ≈ 0.35 × beam | Side-to-side oscillation about longitudinal axis |
| Pitch | {{ site.data.rp2_beaching_gz.natural_periods.pitch_period_s }} s | T ≈ 0.4√LOA + 1.5 | Fore-aft oscillation about transverse axis |
| Heave | {{ site.data.rp2_beaching_gz.natural_periods.heave_period_s }} s | T = 2π√(m/ρgA<sub>wp</sub>) | Vertical oscillation |
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

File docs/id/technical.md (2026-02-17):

---
layout: default
title: Di Balik Layar - Detail Teknis
description: Kapal Hibrida Bertenaga Angin-Surya untuk Daerah Tropis
lang: id
---

# Di Balik Layar

Bagaimana sistem CAD Solar Proa bekerja.

[← Kembali ke Beranda]({{ '/id/' | relative_url }})

---

## Desain Parametrik

Semua desain kapal dibuat menggunakan **pemodelan CAD parametrik** - geometri didefinisikan oleh parameter (dimensi, sudut, posisi) daripada bentuk tetap. Ini berarti:

- **Ubah satu parameter, perbarui seluruh model** - Menyesuaikan panjang lambung secara otomatis menskalakan tiang, balok silang, dan tali-temali
- **Beberapa konfigurasi dari satu sumber** - Model dasar yang sama menghasilkan konfigurasi beaching, close-haul, broad reach, dan pelayaran lainnya
- **Transparansi desain** - Setiap dimensi dapat dilacak ke nilai parameter

Sistem menggunakan [FreeCAD](https://www.freecad.org/) (CAD sumber terbuka) dengan skrip Python yang membaca file parameter, membangun geometri 3D, dan mengekspor render dan file CAD.

---
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

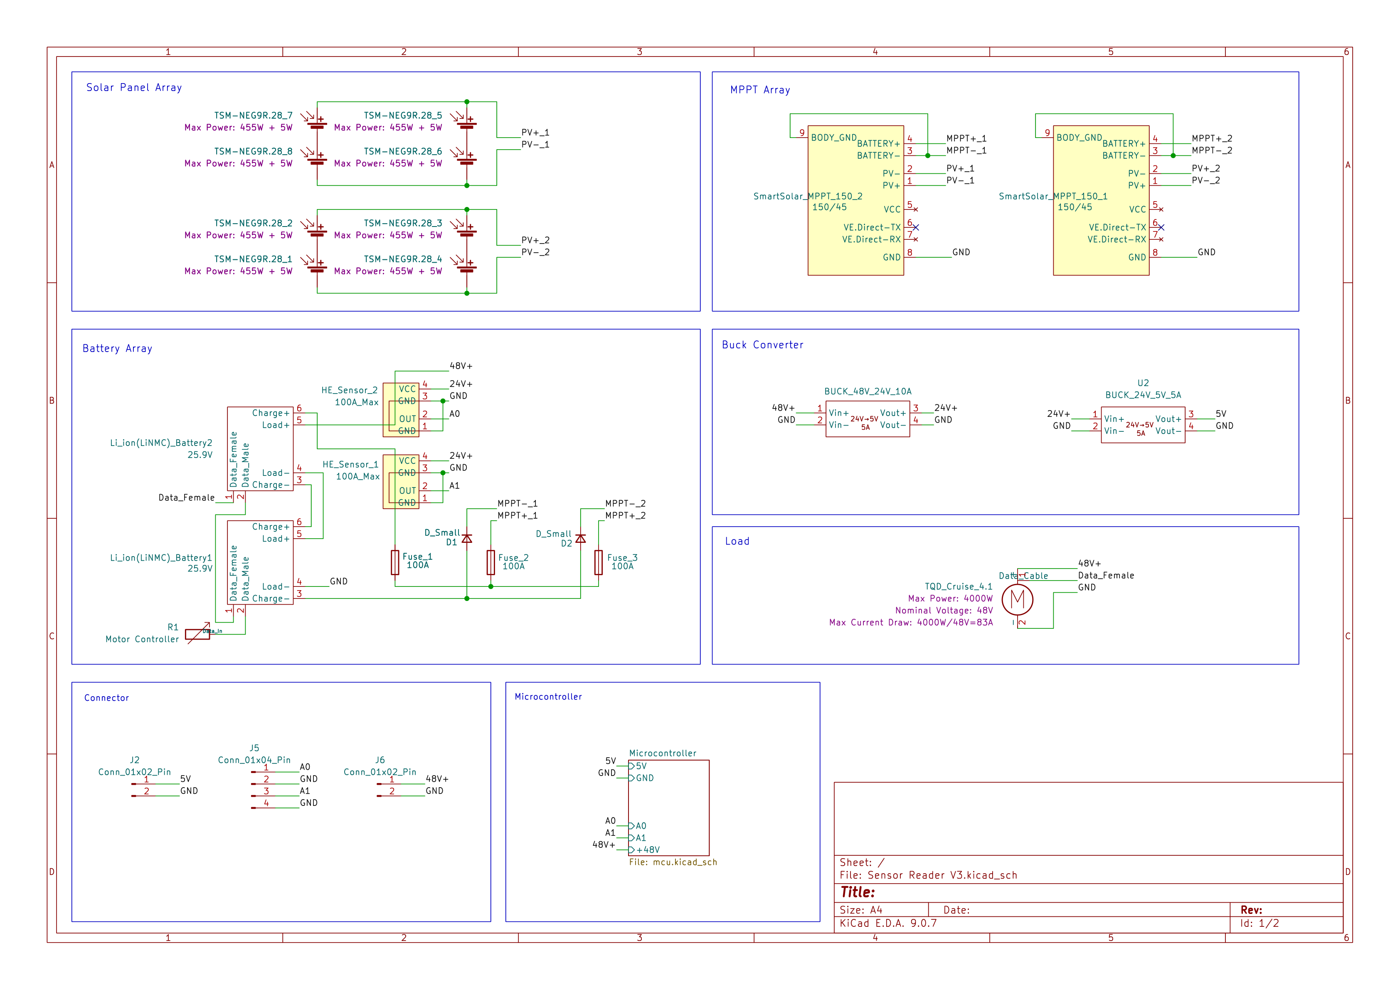
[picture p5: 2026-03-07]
docs/images/circuit_diagrams_temp/Sensor Reader V3.png

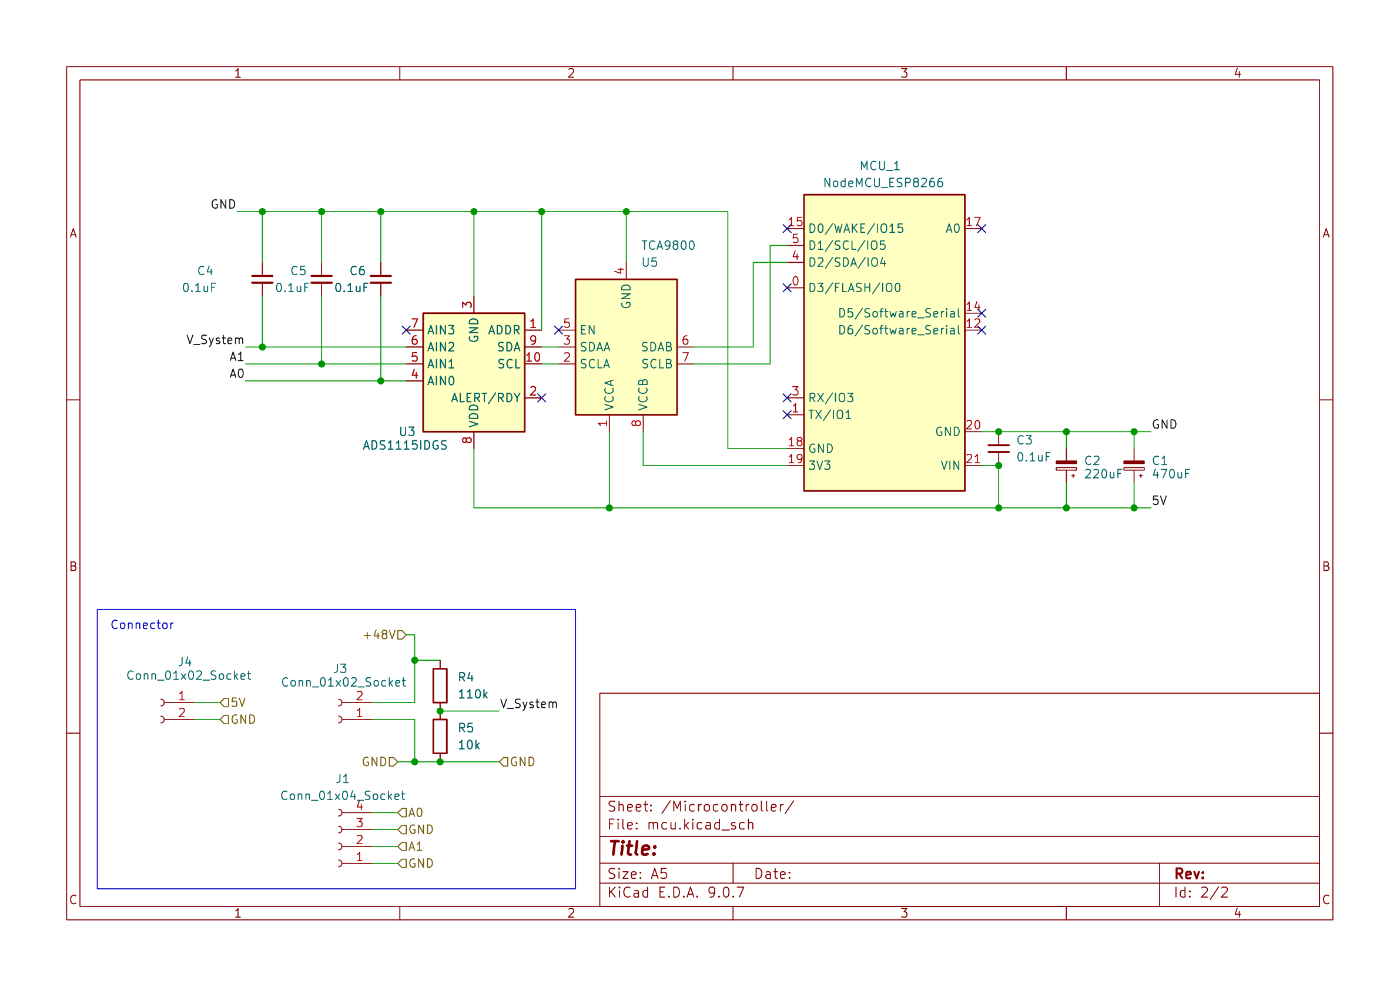
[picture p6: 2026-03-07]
docs/images/circuit_diagrams_temp/Sensor Reader V3-Microcontroller.png

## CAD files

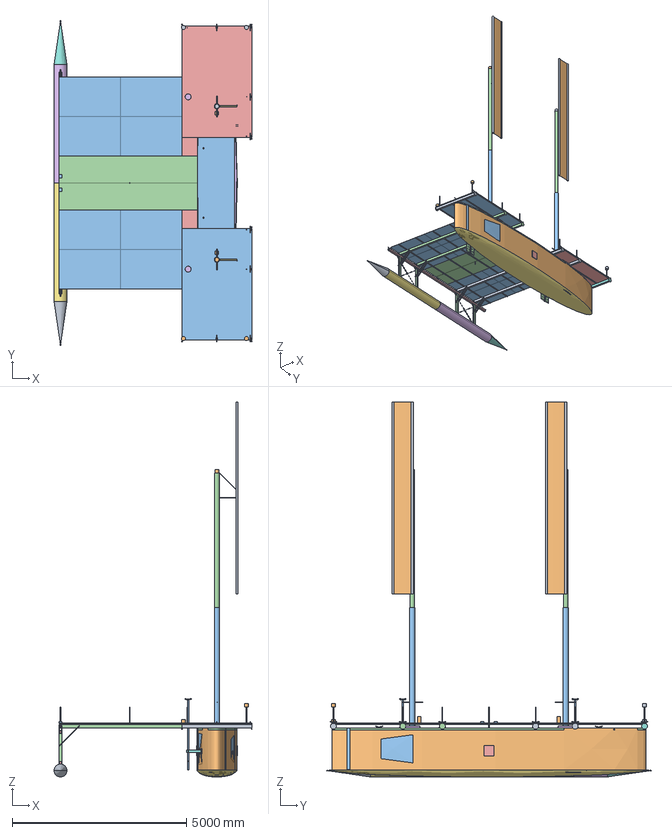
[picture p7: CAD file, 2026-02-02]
docs/downloads/rp2.beaching.step.step
5675.9 x 9300.0 x 10755.0 mm
Aka_0__aluminum_ x 3
Stanchion_0__steel_ x 3
Cleat__steel_ x 3
Gusset_spine_to_aka_right_0__aluminum_ x 3
Gusset_spine_to_aka_left_0__aluminum_ x 3
Gusset_pillar_to_spine_right_0__aluminum_ x 3
Gusset_pillar_to_spine_left_0__aluminum_ x 3
Gusset_pillar_to_ama_top_right_0__aluminum_ x 3
Gusset_pillar_to_ama_top_left_0__aluminum_ x 3
Gusset_pillar_to_ama_bottom_right_0__aluminum_ x 3
Gusset_pillar_to_ama_bottom_left_0__aluminum_ x 3
Gusset_pillar_to_ama_inside_right_0__aluminum_ x 3
Gusset_pillar_to_ama_inside_left_0__aluminum_ x 3
Aka_1__aluminum_ x 3
Stanchion_1__steel_ x 3
Cleat__steel_001 x 3
Gusset_spine_to_aka_right_1__aluminum_ x 3
Gusset_spine_to_aka_left_1__aluminum_ x 3
Gusset_pillar_to_spine_right_1__aluminum_ x 3
Gusset_pillar_to_spine_left_1__aluminum_ x 3
Gusset_pillar_to_ama_top_right_1__aluminum_ x 3
Gusset_pillar_to_ama_top_left_1__aluminum_ x 3
Gusset_pillar_to_ama_bottom_right_1__aluminum_ x 3
Gusset_pillar_to_ama_bottom_left_1__aluminum_ x 3
Gusset_pillar_to_ama_inside_right_1__aluminum_ x 3
Gusset_pillar_to_ama_inside_left_1__aluminum_ x 3
Cross_Brace_1_0__aluminum_ x 3
Cross_Brace_2_0__aluminum_ x 3
Spine_Cleat__steel_ x 3
Aka_End__aluminum_ x 3
Outer_Stanchion__aluminum_ x 3
Outer_Navigation_Light__plastic_ x 3
Outer_Cleat__steel_ x 3
Inner_Stanchion__aluminum_ x 3
Inner_Navigation_Light__plastic_ x 3
Panel_0_0__solar_ x 3
Panel_0_1__solar_dark_ x 3
Panel_1_0__solar_dark_ x 3
Panel_1_1__solar_ x 3
Deck__plywood_ x 3
Center_Cleat__steel_ x 3
Mast_Partner__wood_ x 3
Mast_Step__aluminum_ x 3
Masthead_Navigation_Light__plastic_ x 3
Rudder_Vaka_Mount_A__aluminum_ x 3
Rudder_Vaka_Mount_a_backing_plate__aluminum_ x 3
Rudder_Vaka_Mount_b__aluminum_ x 3
rudder_vaka_mount_b_backing_plate__aluminum_ x 3
Crossdeck__plywood_ x 3
Trap_Cover__plywood_ x 3
Ama_pipe_upper__pvc_ x 3
Ama_pipe_lower__pvc_bottom_ x 3
Ama_Body_Foam__foam_ x 3
Ama_Cone_Upper__pvc_ x 3
Ama_Cone_Lower__pvc_bottom_ x 3
Ama_Cone_Foam__foam_ x 3
Deck_Load__load_ x 3
Sole_Load__load_ x 3
Ama_Load__load_ x 3
X-axis x 24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

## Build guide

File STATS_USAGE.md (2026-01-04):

# Using Statistics in Jekyll Pages

## Overview

The build process automatically generates YAML files in `docs/_data/` containing statistics for each boat configuration. These are available in Jekyll templates as `site.data.<filename>`.

## Example Generated File

`docs/_data/rp2_closehaul.yml`:
```yaml
boat: RP2
configuration: CloseHaul
total_mass_kg: 487.32
total_volume_liters: 1245.67
materials:
  Aluminum:
    mass_kg: 125.60
    volume_liters: 46.52
  Solar panels:
    mass_kg: 72.00
    volume_liters: 15.20
top_components:
  - name: Main Hull
    mass_kg: 156.80
    volume_liters: 580.00
    material: Aluminum
component_count: 45
```

## Usage in Markdown Pages

### Display Total Mass

```markdown
**Total Mass:** {{ site.data.rp2_closehaul.total_mass_kg }} kg
```

### Materials Table

```markdown
| Material | Mass (kg) | Volume (L) |
|----------|-----------|------------|
{% for material in site.data.rp2_closehaul.materials %}
| {{ material[0] }} | {{ material[1].mass_kg }} | {{ material[1].volume_liters }} |
{% endfor %}
```

### Top Components List

```markdown
### Heaviest Components

{% for comp in site.data.rp2_closehaul.top_components limit:5 %}
- **{{ comp.name }}**: {{ comp.mass_kg }} kg ({{ comp.material }})
{% endfor %}
```

### Complete Stats Section

```markdown
## Technical Specifications - {{ site.data.rp2_closehaul.configuration }}

**Total Mass:** {{ site.data.rp2_closehaul.total_mass_kg }} kg  
**Total Volume:** {{ site.data.rp2_closehaul.total_volume_liters }} L  
**Components:** {{ site.data.rp2_closehaul.component_count }}

### Materials Breakdown

<div style="display: grid; grid-template-columns: repeat(auto-fit, minmax(200px, 1fr)); gap: 1em;">
{% for material in site.data.rp2_closehaul.materials %}
  <div style="padding: 1em; border: 1px solid #ddd; border-radius: 4px;">
    <strong>{{ material[0] }}</strong><br>
    Mass: {{ material[1].mass_kg }} kg<br>
    Volume: {{ material[1].volume_liters }} L
  </div>
{% endfor %}
</div>

### Major Components

| Component | Mass (kg) | Material |
|-----------|-----------|----------|
{% for comp in site.data.rp2_closehaul.top_components %}
| {{ comp.name }} | {{ comp.mass_kg }} | {{ comp.material }} |
{% endfor %}
```

## Conditional Loading

Check if data exists before using:

```markdown
{% if site.data.rp2_closehaul %}
  Total mass: {{ site.data.rp2_closehaul.total_mass_kg }} kg
{% else %}
  Statistics not yet generated
{% endif %}
```

## Comparing Configurations

```markdown
| Configuration | Mass (kg) |
|---------------|-----------|
| Close Haul | {{ site.data.rp2_closehaul.total_mass_kg }} |
| Beam Reach | {{ site.data.rp2_beamreach.total_mass_kg }} |
| Broad Reach | {{ site.data.rp2_broadreach.total_mass_kg }} |
```

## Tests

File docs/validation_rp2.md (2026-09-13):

---
layout: default
title: Roti Proa II - Structural Safety Report
---

[← Back to Roti Proa II Overview]({{ '/rp2.html' | relative_url }})
&nbsp;|&nbsp;
[ISO 12215 Traceability →]({{ '/iso_traceability.html' | relative_url }})

---

## Table of Contents

1. [Executive Summary](#executive-summary)
2. [Suspended Ama (Aka Bending)](#1-suspended-ama-aka-bending)
3. [Aka Point Load (Crew Standing)](#2-aka-point-load-crew-standing)
4. [One End Supported (Spine Bending)](#3-one-end-supported-spine-bending)
5. [Mast Wind Loading](#4-mast-wind-loading)
6. [Diagonal Braces (Lateral Loading)](#5-diagonal-braces-lateral-loading)
7. [Wave Slam (Vertical)](#6-wave-slam-vertical)
8. [Frontal Wave Slam](#7-frontal-wave-slam)
9. [Sideways Wave Slam](#8-sideways-wave-slam)
10. [Lifting Sling (Crane Operations)](#9-lifting-sling-crane-operations)
11. [Gunwale Load Distribution](#10-gunwale-load-distribution)
12. [Ama Lift Wind Speed](#11-ama-lift-wind-speed-informational)
13. [Summary Safety Assessment](#summary-safety-assessment)

---

## Executive Summary

The RP2 structural validation suite analyzes the vessel under eleven load scenarios encompassing static loads, dynamic wave impacts, wind forces, and operational conditions. All structural tests pass with safety factors exceeding the required minimum of 2.0.

| Test | Description | Safety Factor | Result |
|---|---|---|---|
| Suspended Ama | Aka cantilever bending | {{ site.data.rp2_beaching_validate_structure.tests[0].summary.strong_axis.safety_factor }} | {{ site.data.rp2_beaching_validate_structure.tests[0].summary.strong_axis.result }} |
| Aka Point Load | Crew standing on aka | {{ site.data.rp2_beaching_validate_structure.tests[1].summary.safety_factor }} | {{ site.data.rp2_beaching_validate_structure.tests[1].summary.result }} |
| One End Supported | Spine bending | {{ site.data.rp2_beaching_validate_structure.tests[2].summary.safety_factor }} | {{ site.data.rp2_beaching_validate_structure.tests[2].summary.result }} |
| Mast Wind Loading | 25-knot wind on sail | {{ site.data.rp2_beaching_validate_structure.tests[3].summary.safety_factor }} | {{ site.data.rp2_beaching_validate_structure.tests[3].summary.result }} |
| Diagonal Braces | Lateral loading (tilted) | {{ site.data.rp2_beaching_validate_structure.tests[4].summary.min_safety_factor }} | {{ site.data.rp2_beaching_validate_structure.tests[4].summary.result }} |
| Wave Slam (Vertical) | 3 m/s impact, 2.5× dynamic | {{ site.data.rp2_beaching_validate_structure.tests[5].summary.min_safety_factor }} | {{ site.data.rp2_beaching_validate_structure.tests[5].summary.result }} |
| Frontal Wave Slam | Fore-aft impact | {{ site.data.rp2_beaching_validate_structure.tests[6].summary.min_safety_factor }} | {{ site.data.rp2_beaching_validate_structure.tests[6].summary.result }} |
| Sideways Wave Slam | Lateral impact | {{ site.data.rp2_beaching_validate_structure.tests[7].summary.min_safety_factor }} | {{ site.data.rp2_beaching_validate_structure.tests[7].summary.result }} |
| Lifting Sling | V-sling crane lift | {{ site.data.rp2_beaching_validate_structure.tests[8].summary.min_safety_factor }} | {{ site.data.rp2_beaching_validate_structure.tests[8].summary.result }} |
| Gunwale Loads | Load distribution to hull | {{ site.data.rp2_beaching_validate_structure.tests[9].summary.min_safety_factor }} | {{ site.data.rp2_beaching_validate_structure.tests[9].summary.result }} |
| Ama Lift Wind Speed | Stability limit | {{ site.data.rp2_beaching_validate_structure.tests[10].summary.ama_lift_windspeed_knots }} knots | INFO |

---

## 1. Suspended Ama (Aka Bending)

### Scenario

The outrigger (ama) loses all buoyancy support—for example, when the boat is heeled such that the ama is lifted completely out of the water, or during transport on a trailer. The full weight of the outrigger structure hangs from the akas (crossbeams), which act as cantilevers extending from the vaka (main hull).

<div style="max-width: 800px; margin: 2em auto;">
  suspended ama
</div>

### Method

Each aka is modeled as a cantilever beam fixed at the vaka gunwale. The outrigger mass is divided into:
- **Tip loads**: Concentrated masses at the aka tips (ama ends, solar panel edges, pillar bases)
- **Distributed loads**: Mass spread along the aka length (solar panels, wiring, structural elements)

The bending moment at the vaka attachment is:

$$M = F_{tip} \times L + F_{distributed} \times \frac{L}{2}$$

where *L* is the cantilever length from vaka to pillar. Bending stress is calculated using beam theory:

$$\sigma = \frac{M}{S}$$

where *S* is the section modulus of the aka's rectangular hollow section (RHS).

### Assumptions

- Aka section: {{ site.data.rp2_beaching_validate_structure.tests[0].summary.aka_dimensions }}
- Material: 6061-T6 aluminum (yield strength 240 MPa)
- Four akas share the load equally
- Fixed support at vaka (conservative—actual connection has some compliance)
- Strong axis (101.6 mm height) resists vertical bending

### Results

| Parameter | Value |
|---|---|
| Outrigger mass | {{ site.data.rp2_beaching_validate_structure.tests[0].summary.outrigger_mass_kg }} kg |
| Cantilever length | {{ site.data.rp2_beaching_validate_structure.tests[0].summary.cantilever_length_m }} m |
| Maximum bending stress | {{ site.data.rp2_beaching_validate_structure.tests[0].summary.strong_axis.max_stress_mpa }} MPa |
| Maximum deflection | {{ site.data.rp2_beaching_validate_structure.tests[0].summary.strong_axis.max_deflection_mm }} mm |
| **Safety Factor** | **{{ site.data.rp2_beaching_validate_structure.tests[0].summary.strong_axis.safety_factor }}** |

---

## 2. Aka Point Load (Crew Standing)

### Scenario

During boarding, maintenance, or emergency situations, crew members may need to stand on the akas. This test validates the aka's capacity to support concentrated crew weight at the worst-case location (center of span).

<div style="max-width: 800px; margin: 2em auto;">
  aka point load
</div>

### Method

The aka is modeled as a simply supported beam with:
- Support at the vaka gunwale (inboard)
- Support at the pillar (outboard, at ama)

A point load at mid-span produces maximum bending moment:

$$M_{max} = \frac{P \times L}{4}$$

where *P* is the crew weight and *L* is the span between supports.

### Assumptions

- Crew mass: {{ site.data.rp2_beaching_validate_structure.tests[1].crew_mass_kg }} kg (approximately two people)
- Load position: center of span (worst case)
- Simply supported conditions (conservative for moment calculation)

### Results

| Parameter | Value |
|---|---|
| Span (vaka to pillar) | {{ site.data.rp2_beaching_validate_structure.tests[1].geometry.span_mm | divided_by: 1000.0 | round: 2 }} m |
| Point load | {{ site.data.rp2_beaching_validate_structure.tests[1].loading.point_load_n | round: 0 }} N |
| Maximum bending stress | {{ site.data.rp2_beaching_validate_structure.tests[1].analysis.max_stress_mpa }} MPa |
| Maximum deflection | {{ site.data.rp2_beaching_validate_structure.tests[1].analysis.max_deflection_mm }} mm |
| **Safety Factor** | **{{ site.data.rp2_beaching_validate_structure.tests[1].summary.safety_factor }}** |

---

## 3. One End Supported (Spine Bending)

### Scenario

The ama is supported at one end only (e.g., resting on a beach or dock) while the other end hangs free. This creates bending in the spine (longitudinal beam connecting the ama sections) as the akas provide intermediate support of varying stiffness.

<div style="max-width: 800px; margin: 2em auto;">
  one end supported
</div>

### Method

The ama is modeled as a continuous beam with:
- Fixed support at one end (beach/dock contact)
- Elastic supports at each aka location (aka flexibility modeled as springs)
- Distributed load from the outrigger structure

The aka spring stiffness is derived from cantilever beam deflection:

$$k_{aka} = \frac{3EI}{L^3}$$

A moment distribution analysis determines reactions at each support and the maximum bending moment in the spine.

### Assumptions

- Spine section: SHS 76.2×76.2×4.5 mm aluminum
- Four akas at equal spacing along the spine
- One end fully fixed (conservative)
- Aka stiffness calculated from cantilever properties

### Results

| Parameter | Value |
|---|---|
| Spine length | {{ site.data.rp2_beaching_validate_structure.tests[2].geometry.spine_length_mm | divided_by: 1000.0 | round: 2 }} m |
| Total outrigger mass | {{ site.data.rp2_beaching_validate_structure.tests[2].ama_analysis.total_outrigger_mass_kg }} kg |
| Maximum spine stress | {{ site.data.rp2_beaching_validate_structure.tests[2].spine_analysis.max_stress_mpa }} MPa |
| **Safety Factor** | **{{ site.data.rp2_beaching_validate_structure.tests[2].summary.safety_factor }}** |

---

## 4. Mast Wind Loading

### Scenario

The mast experiences significant bending loads when sailing in strong winds. The sail force acts at the center of effort (CE), creating a moment about the mast partner (deck-level support).

<div style="max-width: 800px; margin: 2em auto;">
  mast wind
</div>

### Method

Wind force on the sail is estimated per mast using the formula from ISO 12215-10 Clause 7.2 Table 5 (case b, multihull SC1):

$$F = 0.72 \times V^2 \times A$$

where *V* is wind speed in m/s and *A* is total sail area. The 0.72 coefficient already includes the ½ dynamic-pressure term (Note 3: 1.2 × 0.5 × 1.2 = 0.72), so no further division is applied. See [ISO 12215 Structural Traceability](iso_traceability.md) for details. The mast is analyzed for:
- Bending stress at the partner
- Shear stress at the partner
- Combined axial-bending interaction (column buckling)
- Local buckling (D/t ratio check)

The allowable bending force on the cylindrical mast is limited by bending stress at the partner:

$$F_{allowable} = \frac{\sigma_y \times S}{d_{CE}}$$

where *σ_y* is the yield strength (240 MPa for 6061-T6), *S* is the section modulus, and *d_CE* is the distance from the partner to the sail center of effort. The section modulus for a hollow cylindrical tube is:

$$S = \frac{\pi (D^4 - d^4)}{32 D}$$

where *D* is the outer diameter and *d = D - 2t* is the inner diameter. These are standard beam theory formulae applied to the mast geometry, as permitted by ISO 12215-10 Clause 5.3 (which allows any relevant engineering method for stress evaluation).

### Assumptions

- Wind speed: {{ site.data.rp2_beaching_validate_structure.tests[3].wind_speed_knots }} knots
- Sail perpendicular to wind (maximum force)
- Mast section: {{ site.data.rp2_beaching_validate_structure.tests[3].geometry.mast_diameter_mm }} mm diameter × {{ site.data.rp2_beaching_validate_structure.tests[3].geometry.mast_thickness_mm }} mm wall
- Material: 6061-T6 aluminum
- Unstayed mast (no shrouds or stays)
- Wind force per ISO 12215-10 Clause 7.2 Table 5; stress evaluation per Clause 5.3

### Results

| Parameter | Value |
|---|---|
| Sail area | {{ site.data.rp2_beaching_validate_structure.tests[3].geometry.sail_area_m2 }} m² |
| Wind force | {{ site.data.rp2_beaching_validate_structure.tests[3].wind_force_n | round: 0 }} N |
| Bending stress at partner | {{ site.data.rp2_beaching_validate_structure.tests[3].checks.bending_at_partner.stress_mpa }} MPa |
| D/t ratio | {{ site.data.rp2_beaching_validate_structure.tests[3].geometry.d_over_t }} (< 50 OK) |
| **Safety Factor** | **{{ site.data.rp2_beaching_validate_structure.tests[3].summary.safety_factor }}** |

---

## 5. Diagonal Braces (Lateral Loading)

### Scenario

When the boat is tilted (on its side during beaching, or inverted after a capsize), the outrigger weight creates lateral forces on the diagonal braces connecting the pillars to the akas. These braces must resist both compression and tension depending on orientation.

<div style="max-width: 800px; margin: 2em auto;">
  diagonal braces
</div>

### Method

The lateral force equals the outrigger weight when the boat is fully on its side:

$$F_{lateral} = m_{outrigger} \times g$$

This force is distributed among all diagonal braces. Each brace is checked for:
- **Compression**: Euler buckling and compressive yielding
- **Tension**: Tensile yielding

The critical mode is Euler buckling for slender compression members:

$$\sigma_{cr} = \frac{\pi^2 E}{(L/r)^2}$$

where *L/r* is the slenderness ratio.

### Assumptions

- Brace section: {{ site.data.rp2_beaching_validate_structure.tests[4].brace_geometry.section }}
- Brace length: {{ site.data.rp2_beaching_validate_structure.tests[4].brace_geometry.length_mm | round: 0 }} mm
- Brace angle: {{ site.data.rp2_beaching_validate_structure.tests[4].brace_geometry.angle_deg }}° from horizontal
- Number of braces: {{ site.data.rp2_beaching_validate_structure.tests[4].brace_geometry.num_braces }}
- Pin-ended connections (conservative for buckling)

### Results

| Parameter | Value |
|---|---|
| Outrigger mass | {{ site.data.rp2_beaching_validate_structure.tests[4].loading.outrigger_mass_kg }} kg |
| Force per brace | {{ site.data.rp2_beaching_validate_structure.tests[4].compression_check.force_per_brace_n | round: 0 }} N |
| Slenderness ratio | {{ site.data.rp2_beaching_validate_structure.tests[4].compression_check.slenderness_ratio | round: 0 }} |
| Governing mode | {{ site.data.rp2_beaching_validate_structure.tests[4].compression_check.governing_mode }} |
| **Safety Factor** | **{{ site.data.rp2_beaching_validate_structure.tests[4].summary.min_safety_factor }}** |

---

## 6. Wave Slam (Vertical)

### Scenario

When sailing in waves, the ama can slam into the water surface with significant velocity, creating impulsive hydrodynamic loads. This test analyzes vertical wave slam—the ama impacting the water from above.

<div style="max-width: 800px; margin: 2em auto;">
  wave slam vertical
</div>

### Method

Slam pressure is estimated using the water hammer formula:

$$P = \frac{1}{2} \rho V^2 C_p$$

where *V* is impact velocity and *C_p* is a pressure coefficient. A dynamic amplification factor accounts for structural response to impulsive loading.

The load path is: **wave → pillars → diagonal braces → akas → vaka**

The aka is modeled as a propped cantilever with:
- Fixed support at vaka
- Elastic spring support at diagonal brace attachment

### Assumptions

- Impact velocity: {{ site.data.rp2_beaching_validate_structure.tests[5].wave_slam.impact_velocity_ms }} m/s
- Dynamic factor: {{ site.data.rp2_beaching_validate_structure.tests[5].wave_slam.dynamic_factor }}×
- Slam coefficient: {{ site.data.rp2_beaching_validate_structure.tests[5].wave_slam.slam_coefficient }}
- Effective ama area: {{ site.data.rp2_beaching_validate_structure.tests[5].wave_slam.effective_area_m2 }} m² (partial immersion)
- Braces provide elastic support to akas

### Results

| Parameter | Value |
|---|---|
| Slam pressure | {{ site.data.rp2_beaching_validate_structure.tests[5].wave_slam.slam_pressure_kpa }} kPa |
| Total slam force | {{ site.data.rp2_beaching_validate_structure.tests[5].wave_slam.dynamic_slam_force_n | round: 0 }} N |
| Aka stress | {{ site.data.rp2_beaching_validate_structure.tests[5].checks.aka.combined_stress_mpa }} MPa (SF={{ site.data.rp2_beaching_validate_structure.tests[5].checks.aka.safety_factor }}) |
| Brace stress | {{ site.data.rp2_beaching_validate_structure.tests[5].checks.diagonal_braces.compressive_stress_mpa }} MPa (SF={{ site.data.rp2_beaching_validate_structure.tests[5].checks.diagonal_braces.safety_factor }}) |
| Spine stress | {{ site.data.rp2_beaching_validate_structure.tests[5].checks.spine.max_stress_mpa }} MPa (SF={{ site.data.rp2_beaching_validate_structure.tests[5].checks.spine.safety_factor }}) |
| **Governing Component** | **{{ site.data.rp2_beaching_validate_structure.tests[5].summary.governing_component }}** |
| **Safety Factor** | **{{ site.data.rp2_beaching_validate_structure.tests[5].summary.min_safety_factor }}** |

---

## 7. Frontal Wave Slam

### Scenario

The ama encounters a wave head-on, creating a fore-aft impact force. This load is resisted by the X-shaped cross-braces between neighboring pillars.

<div style="max-width: 800px; margin: 2em auto;">
  wave slam frontal
</div>

### Method

Frontal slam force is calculated from the ama's cross-sectional area. The X-braces work as a tension-only system: when loaded, the compression diagonal buckles (due to extreme slenderness), and the tension diagonal carries the full load.

Brace slenderness ratio determines behavior:

$$\lambda = \frac{L}{r} > 100 \implies \text{tension-only behavior}$$

### Assumptions

- Ama frontal area: {{ site.data.rp2_beaching_validate_structure.tests[6].frontal_slam.frontal_area_m2 }} m² (circular cross-section)
- Cross-brace diameter: {{ site.data.rp2_beaching_validate_structure.tests[6].checks.cross_braces.geometry.brace_diameter_mm }} mm (solid rod)
- Brace length: {{ site.data.rp2_beaching_validate_structure.tests[6].checks.cross_braces.geometry.brace_length_mm | round: 0 }} mm
- Number of X-brace pairs: {{ site.data.rp2_beaching_validate_structure.tests[6].checks.cross_braces.geometry.num_x_brace_pairs }}
- Slam coefficient: {{ site.data.rp2_beaching_validate_structure.tests[6].frontal_slam.slam_coefficient }} (blunt body)

### Results

| Parameter | Value |
|---|---|
| Frontal slam force | {{ site.data.rp2_beaching_validate_structure.tests[6].frontal_slam.dynamic_slam_force_n | round: 0 }} N |
| Slenderness ratio | {{ site.data.rp2_beaching_validate_structure.tests[6].checks.cross_braces.slenderness_ratio | round: 0 }} |
| Mode | {{ site.data.rp2_beaching_validate_structure.tests[6].checks.cross_braces.governing_mode }} |
| Tension per brace | {{ site.data.rp2_beaching_validate_structure.tests[6].checks.cross_braces.tension_force_per_brace_n | round: 0 }} N |
| Stress | {{ site.data.rp2_beaching_validate_structure.tests[6].checks.cross_braces.stress_mpa }} MPa |
| **Safety Factor** | **{{ site.data.rp2_beaching_validate_structure.tests[6].summary.min_safety_factor }}** |

---

## 8. Sideways Wave Slam

### Scenario

A wave strikes the ama from the side (athwartships), creating lateral forces. The diagonal pillar braces resist this load in compression.

<div style="max-width: 800px; margin: 2em auto;">
  wave slam sideways
</div>

### Method

The lateral slam force is calculated from the ama's projected side area (length × diameter). The diagonal braces take the horizontal component of this force.

### Assumptions

- Same slam parameters as vertical wave slam
- Diagonal braces at 45° take horizontal load
- Buckling governs for compression braces

### Results

| Parameter | Value |
|---|---|
| Side slam force | {{ site.data.rp2_beaching_validate_structure.tests[7].sideways_slam.dynamic_slam_force_n | round: 0 }} N |
| Force per brace | {{ site.data.rp2_beaching_validate_structure.tests[7].checks.diagonal_braces.axial_force_per_brace_n | round: 0 }} N |
| Euler buckling load | {{ site.data.rp2_beaching_validate_structure.tests[7].checks.diagonal_braces.euler_buckling_load_n | round: 0 }} N |
| **Safety Factor** | **{{ site.data.rp2_beaching_validate_structure.tests[7].summary.min_safety_factor }}** |

---

## 9. Lifting Sling (Crane Operations)

### Scenario

The boat is lifted by crane for launch, haul-out, or transport. A V-sling configuration uses 4 hooks, each connected by two ropes to neighboring akas, distributing the load across all structural elements.

<div style="max-width: 800px; margin: 2em auto;">
  lifting sling
</div>

### Method

The V-sling creates 8 attachment points. Each rope carries a fraction of the vertical load, with increased tension due to the V-angle:

$$T = \frac{F_{vertical}}{\cos(\theta)}$$

Checks include:
- Aka bending (all 4 akas participate)
- Local stress at sling attachment points
- Rope/sling tension capacity
- Global boat bending between supports

### Assumptions

- Total boat mass: {{ site.data.rp2_beaching_validate_structure.tests[8].summary.total_mass_kg }} kg
- V-angle from vertical: {{ site.data.rp2_beaching_validate_structure.tests[8].sling_geometry.v_angle_deg }}°
- Sling type: 50mm polyester flat sling (WLL 2000 kg)
- Aka spacing: {{ site.data.rp2_beaching_validate_structure.tests[8].sling_geometry.aka_spacing_m }} m

### Results

| Component | Stress/Load | Safety Factor |
|---|---|---|
| Aka bending | {{ site.data.rp2_beaching_validate_structure.tests[8].checks.aka_bending.max_stress_mpa }} MPa | {{ site.data.rp2_beaching_validate_structure.tests[8].checks.aka_bending.safety_factor }} |
| Sling attachment | {{ site.data.rp2_beaching_validate_structure.tests[8].checks.sling_point.combined_stress_mpa }} MPa | {{ site.data.rp2_beaching_validate_structure.tests[8].checks.sling_point.safety_factor }} |
| Rope tension | {{ site.data.rp2_beaching_validate_structure.tests[8].checks.rope_tension.rope_tension_n | round: 0 }} N | {{ site.data.rp2_beaching_validate_structure.tests[8].checks.rope_tension.safety_factor }} |
| Global bending | {{ site.data.rp2_beaching_validate_structure.tests[8].checks.global_bending.max_stress_mpa }} MPa | {{ site.data.rp2_beaching_validate_structure.tests[8].checks.global_bending.safety_factor }} |
| **Governing** | **{{ site.data.rp2_beaching_validate_structure.tests[8].summary.governing_component }}** | **{{ site.data.rp2_beaching_validate_structure.tests[8].summary.min_safety_factor }}** |

---

## 10. Gunwale Load Distribution

### Scenario

The akas transfer all outrigger loads to the vaka through the gunwales. This test validates that the wooden gunwales (3" × 2", fiberglass-bonded to the hull) can carry and distribute the concentrated aka loads.

<div style="max-width: 800px; margin: 2em auto;">
  gunwale loads
</div>

### Method

The gunwale is modeled as a beam on elastic foundation. The characteristic length over which load spreads is:

$$\lambda = \left(\frac{4EI}{k}\right)^{0.25}$$

where *k* is the foundation stiffness (hull skin supporting the gunwale).

Checks include:
- Gunwale bending stress
- Bearing stress (wood perpendicular to grain)
- Bond shear (fiberglass joint to hull)

### Assumptions

- Gunwale section: {{ site.data.rp2_beaching_validate_structure.tests[9].gunwale_section.width_mm | round: 1 }} × {{ site.data.rp2_beaching_validate_structure.tests[9].gunwale_section.height_mm }} mm
- Material: Douglas fir or similar (allowable bending 50 MPa, bearing 10 MPa)
- Fiberglass bond allowable shear: 5 MPa
- Design load: wave slam (governs over static suspended ama)
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

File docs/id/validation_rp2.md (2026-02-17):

---
layout: default
title: Roti Proa II - Laporan Keselamatan Struktural
description: Kapal Hibrida Bertenaga Angin-Surya untuk Daerah Tropis
lang: id
---

# Laporan Keselamatan Struktural: Roti Proa II

Laporan ini mendokumentasikan analisis validasi struktural untuk Roti Proa II (RP2), kapal wisata harian surya-listrik 9 meter. Semua analisis menggunakan **konfigurasi beaching** (layar digulung, kemudi diangkat) yang mewakili kapal dalam kondisi diam paling umum.

**Tanggal Validasi:** Dihasilkan secara otomatis dari model CAD
**Faktor Keamanan yang Diperlukan:** {{ site.data.rp2_beaching_validate_structure.min_safety_factor_required }}
**Hasil Keseluruhan:** {% if site.data.rp2_beaching_validate_structure.passed %}**LULUS**{% else %}**GAGAL**{% endif %}

[← Kembali ke Ringkasan RP2]({{ '/id/rp2.html' | relative_url }})

---

## Daftar Isi

1. [Ringkasan Eksekutif](#ringkasan-eksekutif)
2. [Ama Tergantung (Lentur Aka)](#1-ama-tergantung-lentur-aka)
3. [Beban Titik Aka (Kru Berdiri)](#2-beban-titik-aka-kru-berdiri)
4. [Satu Ujung Ditopang (Lentur Spine)](#3-satu-ujung-ditopang-lentur-spine)
5. [Beban Angin Tiang](#4-beban-angin-tiang)
6. [Penopang Diagonal (Beban Lateral)](#5-penopang-diagonal-beban-lateral)
7. [Hantaman Gelombang (Vertikal)](#6-hantaman-gelombang-vertikal)
8. [Hantaman Gelombang Frontal](#7-hantaman-gelombang-frontal)
9. [Hantaman Gelombang Samping](#8-hantaman-gelombang-samping)
10. [Sling Pengangkat (Operasi Crane)](#9-sling-pengangkat-operasi-crane)
11. [Distribusi Beban Gunwale](#10-distribusi-beban-gunwale)
12. [Kecepatan Angin Angkat Ama](#11-kecepatan-angin-angkat-ama-informasional)
13. [Ringkasan Penilaian Keselamatan](#ringkasan-penilaian-keselamatan)

---

## Ringkasan Eksekutif

Rangkaian validasi struktural RP2 menganalisis kapal di bawah sebelas skenario beban yang mencakup beban statis, dampak gelombang dinamis, gaya angin, dan kondisi operasional. Semua tes struktural lulus dengan faktor keamanan melebihi minimum yang diperlukan yaitu 2,0.

| Tes | Deskripsi | Faktor Keamanan | Hasil |
|-----|---|---|---|
| Ama Tergantung | Lentur kantilever aka | {{ site.data.rp2_beaching_validate_structure.tests[0].summary.strong_axis.safety_factor }} | {{ site.data.rp2_beaching_validate_structure.tests[0].summary.strong_axis.result }} |
| Beban Titik Aka | Kru berdiri di aka | {{ site.data.rp2_beaching_validate_structure.tests[1].summary.safety_factor }} | {{ site.data.rp2_beaching_validate_structure.tests[1].summary.result }} |
| Satu Ujung Ditopang | Lentur spine | {{ site.data.rp2_beaching_validate_structure.tests[2].summary.safety_factor }} | {{ site.data.rp2_beaching_validate_structure.tests[2].summary.result }} |
| Beban Angin Tiang | Angin 25 knot pada layar | {{ site.data.rp2_beaching_validate_structure.tests[3].summary.safety_factor }} | {{ site.data.rp2_beaching_validate_structure.tests[3].summary.result }} |
| Penopang Diagonal | Beban lateral (miring) | {{ site.data.rp2_beaching_validate_structure.tests[4].summary.min_safety_factor }} | {{ site.data.rp2_beaching_validate_structure.tests[4].summary.result }} |
| Hantaman Gelombang (Vertikal) | Dampak 3 m/s, dinamis 2,5× | {{ site.data.rp2_beaching_validate_structure.tests[5].summary.min_safety_factor }} | {{ site.data.rp2_beaching_validate_structure.tests[5].summary.result }} |
| Hantaman Gelombang Frontal | Dampak depan-belakang | {{ site.data.rp2_beaching_validate_structure.tests[6].summary.min_safety_factor }} | {{ site.data.rp2_beaching_validate_structure.tests[6].summary.result }} |
| Hantaman Gelombang Samping | Dampak lateral | {{ site.data.rp2_beaching_validate_structure.tests[7].summary.min_safety_factor }} | {{ site.data.rp2_beaching_validate_structure.tests[7].summary.result }} |
| Sling Pengangkat | Angkat crane V-sling | {{ site.data.rp2_beaching_validate_structure.tests[8].summary.min_safety_factor }} | {{ site.data.rp2_beaching_validate_structure.tests[8].summary.result }} |
| Beban Gunwale | Distribusi beban ke lambung | {{ site.data.rp2_beaching_validate_structure.tests[9].summary.min_safety_factor }} | {{ site.data.rp2_beaching_validate_structure.tests[9].summary.result }} |
| Kecepatan Angin Angkat Ama | Batas stabilitas | {{ site.data.rp2_beaching_validate_structure.tests[10].summary.ama_lift_windspeed_knots }} knot | INFO |

---

## 1. Ama Tergantung (Lentur Aka)

### Skenario

Cadik (ama) kehilangan semua dukungan daya apung—misalnya, ketika kapal miring sehingga ama terangkat sepenuhnya keluar dari air, atau selama transportasi di trailer. Seluruh berat struktur cadik tergantung dari aka (balok silang), yang bertindak sebagai kantilever yang memanjang dari vaka (lambung utama).

<div style="max-width: 800px; margin: 2em auto;">
  ama tergantung
</div>

### Metode

Setiap aka dimodelkan sebagai balok kantilever yang terjepit di gunwale vaka. Massa cadik dibagi menjadi:
- **Beban ujung**: Massa terkonsentrasi di ujung aka (ujung ama, tepi panel surya, dasar pilar)
- **Beban terdistribusi**: Massa tersebar sepanjang panjang aka (panel surya, kabel, elemen struktural)

Momen lentur pada sambungan vaka adalah:

$$M = F_{ujung} \times L + F_{terdistribusi} \times \frac{L}{2}$$

di mana *L* adalah panjang kantilever dari vaka ke pilar. Tegangan lentur dihitung menggunakan teori balok:

$$\sigma = \frac{M}{S}$$

di mana *S* adalah modulus penampang dari penampang berongga persegi panjang (RHS) aka.

### Asumsi

- Penampang aka: {{ site.data.rp2_beaching_validate_structure.tests[0].summary.aka_dimensions }}
- Material: Aluminium 6061-T6 (kekuatan luluh 240 MPa)
- Empat aka berbagi beban secara merata
- Tumpuan terjepit di vaka (konservatif—sambungan aktual memiliki beberapa kelenturan)
- Sumbu kuat (tinggi 101,6 mm) menahan lentur vertikal

### Hasil

| Parameter | Nilai |
|---|---|
| Massa cadik | {{ site.data.rp2_beaching_validate_structure.tests[0].summary.outrigger_mass_kg }} kg |
| Panjang kantilever | {{ site.data.rp2_beaching_validate_structure.tests[0].summary.cantilever_length_m }} m |
| Tegangan lentur maksimum | {{ site.data.rp2_beaching_validate_structure.tests[0].summary.strong_axis.max_stress_mpa }} MPa |
| Defleksi maksimum | {{ site.data.rp2_beaching_validate_structure.tests[0].summary.strong_axis.max_deflection_mm }} mm |
| **Faktor Keamanan** | **{{ site.data.rp2_beaching_validate_structure.tests[0].summary.strong_axis.safety_factor }}** |

---

## 2. Beban Titik Aka (Kru Berdiri)

### Skenario

Selama naik kapal, pemeliharaan, atau situasi darurat, anggota kru mungkin perlu berdiri di aka. Tes ini memvalidasi kapasitas aka untuk menopang berat kru terkonsentrasi di lokasi terburuk (tengah bentang).

<div style="max-width: 800px; margin: 2em auto;">
  beban titik aka
</div>

### Metode

Aka dimodelkan sebagai balok dengan tumpuan sederhana dengan:
- Tumpuan di gunwale vaka (dalam)
- Tumpuan di pilar (luar, di ama)

Beban titik di tengah bentang menghasilkan momen lentur maksimum:

$$M_{max} = \frac{P \times L}{4}$$

di mana *P* adalah berat kru dan *L* adalah bentang antara tumpuan.

### Asumsi

- Massa kru: {{ site.data.rp2_beaching_validate_structure.tests[1].crew_mass_kg }} kg (sekitar dua orang)
- Posisi beban: tengah bentang (kasus terburuk)
- Kondisi tumpuan sederhana (konservatif untuk perhitungan momen)

### Hasil

| Parameter | Nilai |
|---|---|
| Bentang (vaka ke pilar) | {{ site.data.rp2_beaching_validate_structure.tests[1].geometry.span_mm | divided_by: 1000.0 | round: 2 }} m |
| Beban titik | {{ site.data.rp2_beaching_validate_structure.tests[1].loading.point_load_n | round: 0 }} N |
| Tegangan lentur maksimum | {{ site.data.rp2_beaching_validate_structure.tests[1].analysis.max_stress_mpa }} MPa |
| Defleksi maksimum | {{ site.data.rp2_beaching_validate_structure.tests[1].analysis.max_deflection_mm }} mm |
| **Faktor Keamanan** | **{{ site.data.rp2_beaching_validate_structure.tests[1].summary.safety_factor }}** |

---

## 3. Satu Ujung Ditopang (Lentur Spine)

### Skenario

Ama ditopang di satu ujung saja (misalnya, beristirahat di pantai atau dermaga) sementara ujung lainnya menggantung bebas. Ini menciptakan lentur pada spine (balok longitudinal yang menghubungkan bagian ama) saat aka memberikan dukungan perantara dengan kekakuan bervariasi.

<div style="max-width: 800px; margin: 2em auto;">
  satu ujung ditopang
</div>

### Metode

Ama dimodelkan sebagai balok kontinu dengan:
- Tumpuan terjepit di satu ujung (kontak pantai/dermaga)
- Tumpuan elastis di setiap lokasi aka (fleksibilitas aka dimodelkan sebagai pegas)
- Beban terdistribusi dari struktur cadik

Kekakuan pegas aka diturunkan dari defleksi balok kantilever:

$$k_{aka} = \frac{3EI}{L^3}$$

Analisis distribusi momen menentukan reaksi di setiap tumpuan dan momen lentur maksimum pada spine.

### Asumsi

- Penampang spine: SHS 76,2×76,2×4,5 mm aluminium
- Empat aka dengan jarak sama sepanjang spine
- Satu ujung sepenuhnya terjepit (konservatif)
- Kekakuan aka dihitung dari properti kantilever

### Hasil

| Parameter | Nilai |
|---|---|
| Panjang spine | {{ site.data.rp2_beaching_validate_structure.tests[2].geometry.spine_length_mm | divided_by: 1000.0 | round: 2 }} m |
| Total massa cadik | {{ site.data.rp2_beaching_validate_structure.tests[2].ama_analysis.total_outrigger_mass_kg }} kg |
| Tegangan spine maksimum | {{ site.data.rp2_beaching_validate_structure.tests[2].spine_analysis.max_stress_mpa }} MPa |
| **Faktor Keamanan** | **{{ site.data.rp2_beaching_validate_structure.tests[2].summary.safety_factor }}** |

---

## 4. Beban Angin Tiang

### Skenario

Tiang mengalami beban lentur yang signifikan saat berlayar dalam angin kencang. Gaya layar bekerja pada pusat usaha (CE), menciptakan momen terhadap mast partner (tumpuan setingkat dek).

<div style="max-width: 800px; margin: 2em auto;">
  angin tiang
</div>

### Metode

Gaya angin pada layar diestimasi menggunakan:

$$F = \frac{1}{2} \rho V^2 C_d A$$

di mana *ρ* adalah kerapatan udara, *V* adalah kecepatan angin, *C_d* adalah koefisien hambatan, dan *A* adalah luas layar. Tiang dianalisis untuk:
- Tegangan lentur di partner
- Tegangan geser di partner
- Interaksi aksial-lentur gabungan (tekuk kolom)
- Tekuk lokal (pemeriksaan rasio D/t)

### Asumsi

- Kecepatan angin: {{ site.data.rp2_beaching_validate_structure.tests[3].wind_speed_knots }} knot
- Layar tegak lurus terhadap angin (gaya maksimum)
- Penampang tiang: diameter {{ site.data.rp2_beaching_validate_structure.tests[3].geometry.mast_diameter_mm }} mm × dinding {{ site.data.rp2_beaching_validate_structure.tests[3].geometry.mast_thickness_mm }} mm
- Material: Aluminium 6061-T6
- Tiang tanpa stay (tanpa shroud atau stay)

### Hasil

| Parameter | Nilai |
|---|---|
| Luas layar | {{ site.data.rp2_beaching_validate_structure.tests[3].geometry.sail_area_m2 }} m² |
| Gaya angin | {{ site.data.rp2_beaching_validate_structure.tests[3].wind_force_n | round: 0 }} N |
| Tegangan lentur di partner | {{ site.data.rp2_beaching_validate_structure.tests[3].checks.bending_at_partner.stress_mpa }} MPa |
| Rasio D/t | {{ site.data.rp2_beaching_validate_structure.tests[3].geometry.d_over_t }} (< 50 OK) |
| **Faktor Keamanan** | **{{ site.data.rp2_beaching_validate_structure.tests[3].summary.safety_factor }}** |

---

## 5. Penopang Diagonal (Beban Lateral)

### Skenario

Ketika kapal miring (di sisinya selama beaching, atau terbalik setelah capsize), berat cadik menciptakan gaya lateral pada penopang diagonal yang menghubungkan pilar ke aka. Penopang ini harus menahan kompresi dan tarik tergantung pada orientasi.

<div style="max-width: 800px; margin: 2em auto;">
  penopang diagonal
</div>

### Metode

Gaya lateral sama dengan berat cadik ketika kapal sepenuhnya di sisinya:

$$F_{lateral} = m_{cadik} \times g$$

Gaya ini didistribusikan di antara semua penopang diagonal. Setiap penopang diperiksa untuk:
- **Kompresi**: Tekuk Euler dan luluh tekan
- **Tarik**: Luluh tarik

Mode kritis adalah tekuk Euler untuk elemen kompresi langsing:

$$\sigma_{cr} = \frac{\pi^2 E}{(L/r)^2}$$

di mana *L/r* adalah rasio kelangsingan.

### Asumsi

- Penampang penopang: {{ site.data.rp2_beaching_validate_structure.tests[4].brace_geometry.section }}
- Panjang penopang: {{ site.data.rp2_beaching_validate_structure.tests[4].brace_geometry.length_mm | round: 0 }} mm
- Sudut penopang: {{ site.data.rp2_beaching_validate_structure.tests[4].brace_geometry.angle_deg }}° dari horizontal
- Jumlah penopang: {{ site.data.rp2_beaching_validate_structure.tests[4].brace_geometry.num_braces }}
- Sambungan berujung pin (konservatif untuk tekuk)

### Hasil

| Parameter | Nilai |
|---|---|
| Massa cadik | {{ site.data.rp2_beaching_validate_structure.tests[4].loading.outrigger_mass_kg }} kg |
| Gaya per penopang | {{ site.data.rp2_beaching_validate_structure.tests[4].compression_check.force_per_brace_n | round: 0 }} N |
| Rasio kelangsingan | {{ site.data.rp2_beaching_validate_structure.tests[4].compression_check.slenderness_ratio | round: 0 }} |
| Mode dominan | {{ site.data.rp2_beaching_validate_structure.tests[4].compression_check.governing_mode }} |
| **Faktor Keamanan** | **{{ site.data.rp2_beaching_validate_structure.tests[4].summary.min_safety_factor }}** |

---

## 6. Hantaman Gelombang (Vertikal)

### Skenario

Saat berlayar dalam gelombang, ama dapat menghantam permukaan air dengan kecepatan signifikan, menciptakan beban hidrodinamik impulsif. Tes ini menganalisis hantaman gelombang vertikal—ama menghantam air dari atas.

<div style="max-width: 800px; margin: 2em auto;">
  hantaman gelombang vertikal
</div>

### Metode

Tekanan hantaman diestimasi menggunakan rumus palu air:

$$P = \frac{1}{2} \rho V^2 C_p$$

di mana *V* adalah kecepatan dampak dan *C_p* adalah koefisien tekanan. Faktor amplifikasi dinamis memperhitungkan respons struktural terhadap pembebanan impulsif.

Jalur beban adalah: **gelombang → pilar → penopang diagonal → aka → vaka**

Aka dimodelkan sebagai kantilever yang ditopang dengan:
- Tumpuan terjepit di vaka
- Tumpuan pegas elastis di sambungan penopang diagonal

### Asumsi

- Kecepatan dampak: {{ site.data.rp2_beaching_validate_structure.tests[5].wave_slam.impact_velocity_ms }} m/s
- Faktor dinamis: {{ site.data.rp2_beaching_validate_structure.tests[5].wave_slam.dynamic_factor }}×
- Koefisien hantaman: {{ site.data.rp2_beaching_validate_structure.tests[5].wave_slam.slam_coefficient }}
- Luas efektif ama: {{ site.data.rp2_beaching_validate_structure.tests[5].wave_slam.effective_area_m2 }} m² (perendaman parsial)
- Penopang memberikan dukungan elastis ke aka

### Hasil

| Parameter | Nilai |
|---|---|
| Tekanan hantaman | {{ site.data.rp2_beaching_validate_structure.tests[5].wave_slam.slam_pressure_kpa }} kPa |
| Total gaya hantaman | {{ site.data.rp2_beaching_validate_structure.tests[5].wave_slam.dynamic_slam_force_n | round: 0 }} N |
| Tegangan aka | {{ site.data.rp2_beaching_validate_structure.tests[5].checks.aka.combined_stress_mpa }} MPa (SF={{ site.data.rp2_beaching_validate_structure.tests[5].checks.aka.safety_factor }}) |
| Tegangan penopang | {{ site.data.rp2_beaching_validate_structure.tests[5].checks.diagonal_braces.compressive_stress_mpa }} MPa (SF={{ site.data.rp2_beaching_validate_structure.tests[5].checks.diagonal_braces.safety_factor }}) |
| Tegangan spine | {{ site.data.rp2_beaching_validate_structure.tests[5].checks.spine.max_stress_mpa }} MPa (SF={{ site.data.rp2_beaching_validate_structure.tests[5].checks.spine.safety_factor }}) |
| **Komponen Dominan** | **{{ site.data.rp2_beaching_validate_structure.tests[5].summary.governing_component }}** |
| **Faktor Keamanan** | **{{ site.data.rp2_beaching_validate_structure.tests[5].summary.min_safety_factor }}** |

---

## 7. Hantaman Gelombang Frontal

### Skenario

Ama menghadapi gelombang secara langsung, menciptakan gaya dampak depan-belakang. Beban ini ditahan oleh penopang silang bentuk-X antara pilar bersebelahan.

<div style="max-width: 800px; margin: 2em auto;">
  hantaman gelombang frontal
</div>

### Metode

Gaya hantaman frontal dihitung dari luas penampang melintang ama. Penopang-X bekerja sebagai sistem tarik-saja: saat dibebani, diagonal kompresi tekuk (karena kelangsingan ekstrem), dan diagonal tarik membawa beban penuh.

Rasio kelangsingan penopang menentukan perilaku:

$$\lambda = \frac{L}{r} > 100 \implies \text{perilaku tarik-saja}$$
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

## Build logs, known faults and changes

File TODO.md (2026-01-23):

# TODOs for this repo

- renderings are often ambiguous regarding whether the sails are convex or concave
  from the point of view of the camera

- add roll and pitch period calculation

- add mast sections

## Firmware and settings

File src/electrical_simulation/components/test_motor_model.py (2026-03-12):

"""
Unit tests for BLDC Motor Physics Model.

Run with: python -m pytest src/electrical_simulation/components/test_motor_model.py
"""

import math
import pytest
from .motor_model import (
    MotorModel, 
    MotorConstants, 
    PropellerConstants,
    MotorOperatingPoint,
    create_motor_model_from_config,
    derive_propeller_kp
)


class TestMotorConstants:
    """Test motor constant calculations."""
    
    def test_ke_from_kv(self):
        """Ke should be derived correctly from Kv."""
        motor = MotorConstants(kv=100, resistance=0.1)
        expected_ke = 60.0 / (2.0 * math.pi * 100)
        assert abs(motor.ke - expected_ke) < 1e-10
    
    def test_kt_equals_ke(self):
        """For BLDC motors, Kt = Ke."""
        motor = MotorConstants(kv=150, resistance=0.05)
        assert motor.kt == motor.ke
    
    def test_default_no_load_current(self):
        """No-load current defaults to 0."""
        motor = MotorConstants(kv=100, resistance=0.1)
        assert motor.no_load_current == 0.0


class TestMotorModelZeroThrottle:
    """Test zero throttle behavior."""
    
    def test_zero_throttle_returns_zero_power(self):
        """Zero throttle should produce zero power."""
        motor = MotorConstants(kv=150, resistance=0.05)
        model = MotorModel(motor, bus_voltage=48.0)
        
        op = model.calculate_operating_point(0.0)
        
        assert op.power_electrical_w == 0.0
        assert op.power_mechanical_w == 0.0
        assert op.speed_rpm == 0.0
        assert op.current_amps == 0.0
        assert not op.is_stalled
    
    def test_negative_throttle_treated_as_zero(self):
        """Negative throttle should be treated as zero."""
        motor = MotorConstants(kv=150, resistance=0.05)
        model = MotorModel(motor, bus_voltage=48.0)
        
        op = model.calculate_operating_point(-0.5)
        
        assert op.power_electrical_w == 0.0


class TestMotorModelFullThrottle:
    """Test full throttle behavior."""
    
    def test_full_throttle_produces_power(self):
        """Full throttle should produce positive power."""
        motor = MotorConstants(kv=150, resistance=0.05)
        propeller = PropellerConstants(kp=0.001)
        model = MotorModel(motor, propeller, bus_voltage=48.0)
        
        op = model.calculate_operating_point(1.0)
        
        assert op.power_electrical_w > 0
        assert op.power_mechanical_w > 0
        assert op.speed_rpm > 0
        assert op.current_amps > 0
    
    def test_efficiency_between_zero_and_one(self):
        """Motor efficiency should be between 0 and 1."""
        motor = MotorConstants(kv=150, resistance=0.05)
        propeller = PropellerConstants(kp=0.001)
        model = MotorModel(motor, propeller, bus_voltage=48.0)
        
        op = model.calculate_operating_point(1.0)
        
        assert 0 < op.efficiency <= 1.0


class TestMotorModelPropellerEquilibrium:
    """Test propeller load coupling."""
    
    def test_equilibrium_convergence(self):
        """Motor should find equilibrium with propeller load."""
        motor = MotorConstants(kv=150, resistance=0.05, no_load_current=1.0)
        propeller = PropellerConstants(kp=0.0008)
        model = MotorModel(motor, propeller, bus_voltage=48.0)
        
        op = model.calculate_operating_point(0.75)
        
        # At equilibrium, motor torque should equal propeller torque
        kt = motor.kt
        kp = propeller.kp
        omega = op.speed_rad_s
        
        # current_amps IS the winding current; net torque uses (I - I_nl)
        motor_torque = kt * (op.current_amps - motor.no_load_current)
        propeller_torque = kp * omega * omega
        
        # Allow some tolerance for convergence
        assert abs(motor_torque - propeller_torque) < 0.1
    
    def test_higher_throttle_higher_speed(self):
        """Higher throttle should result in higher speed."""
        motor = MotorConstants(kv=150, resistance=0.05)
        propeller = PropellerConstants(kp=0.0008)
        model = MotorModel(motor, propeller, bus_voltage=48.0)
        
        op_low = model.calculate_operating_point(0.3)
        op_mid = model.calculate_operating_point(0.6)
        op_high = model.calculate_operating_point(0.9)
        
        assert op_low.speed_rpm < op_mid.speed_rpm < op_high.speed_rpm
    
    def test_higher_throttle_higher_power(self):
        """Higher throttle should result in higher power."""
        motor = MotorConstants(kv=150, resistance=0.05)
        propeller = PropellerConstants(kp=0.0008)
        model = MotorModel(motor, propeller, bus_voltage=48.0)
        
        op_low = model.calculate_operating_point(0.3)
        op_high = model.calculate_operating_point(0.9)
        
        assert op_low.power_electrical_w < op_high.power_electrical_w


class TestMotorModelSimpleMode:
    """Test model without propeller coupling."""
    
    def test_simple_model_without_propeller(self):
        """Model should work without propeller constants."""
        motor = MotorConstants(kv=150, resistance=0.05)
        model = MotorModel(motor, propeller=None, bus_voltage=48.0)
        
        op = model.calculate_operating_point(0.5)
        
        assert op.power_electrical_w > 0
        assert op.speed_rpm > 0


class TestMotorModelConvenienceMethods:
    """Test convenience interface methods."""
    
    def test_get_power_from_throttle(self):
        """get_power_from_throttle should return electrical power."""
        motor = MotorConstants(kv=150, resistance=0.05)
        propeller = PropellerConstants(kp=0.0008)
        model = MotorModel(motor, propeller, bus_voltage=48.0)
        
        power = model.get_power_from_throttle(0.5)
        op = model.calculate_operating_point(0.5)
        
        assert power == op.power_electrical_w
    
    def test_get_efficiency_at_throttle(self):
        """get_efficiency_at_throttle should return efficiency."""
        motor = MotorConstants(kv=150, resistance=0.05)
        propeller = PropellerConstants(kp=0.0008)
        model = MotorModel(motor, propeller, bus_voltage=48.0)
        
        efficiency = model.get_efficiency_at_throttle(0.5)
        op = model.calculate_operating_point(0.5)
        
        assert efficiency == op.efficiency


class TestCreateMotorModelFromConfig:
    """Test factory function for creating motor model from config."""
    
    def test_returns_none_without_required_constants(self):
        """Should return None if motor constants not provided."""
        config = {"total_power": 2000, "nominal_voltage": 48.0}
        model = create_motor_model_from_config(config, bus_voltage=48.0)
        
        assert model is None
    
    def test_creates_model_with_motor_constants(self):
        """Should create model when motor constants provided."""
        config = {
            "motor_kv": 150,
            "motor_resistance": 0.05,
            "total_power": 2000
        }
        model = create_motor_model_from_config(config, bus_voltage=48.0)
        
        assert model is not None
        assert isinstance(model, MotorModel)
    
    def test_creates_model_with_propeller(self):
        """Should include propeller when propeller_kp provided."""
        config = {
            "motor_kv": 150,
            "motor_resistance": 0.05,
            "propeller_kp": 0.0008,
            "total_power": 2000
        }
        model = create_motor_model_from_config(config, bus_voltage=48.0)
        
        assert model is not None
        assert model.propeller is not None
        assert model.propeller.kp == 0.0008
    
    def test_no_load_current_optional(self):
        """No-load current should default to 0 if not provided."""
        config = {
            "motor_kv": 150,
            "motor_resistance": 0.05
        }
        model = create_motor_model_from_config(config, bus_voltage=48.0)
        
        assert model.motor.no_load_current == 0.0


class TestBackwardCompatibility:
    """Test backward compatibility with existing configurations."""
    
    def test_linear_config_returns_none(self):
        """Config without motor physics should return None for linear fallback."""
        linear_config = {
            "total_power": 2000,
            "nominal_voltage": 24.0
        }
        model = create_motor_model_from_config(linear_config, bus_voltage=24.0)
        
        assert model is None
    
    def test_torqeedo_config_creates_model(self):
        """Torqeedo config with motor physics should create model."""
        torqeedo_config = {
            "total_power": 2000,
            "nominal_voltage": 24.0,
            "motor_kv": 150,
            "motor_resistance": 0.05,
            "motor_no_load_current": 1.5,
            "propeller_kp": 0.0008
        }
        model = create_motor_model_from_config(torqeedo_config, bus_voltage=24.0)
        
        assert model is not None
        assert model.motor.kv == 150
        assert model.propeller is not None


class TestNonLinearPowerScaling:
    """Verify power scaling is non-linear with propeller load."""
    
    def test_power_not_linear_with_throttle(self):
        """Power should NOT scale linearly with throttle when using propeller."""
        motor = MotorConstants(kv=150, resistance=0.05)
        propeller = PropellerConstants(kp=0.0008)
        model = MotorModel(motor, propeller, bus_voltage=48.0)
        
        p_25 = model.get_power_from_throttle(0.25)
        p_50 = model.get_power_from_throttle(0.50)
        p_75 = model.get_power_from_throttle(0.75)
        p_100 = model.get_power_from_throttle(1.0)
        
        # If linear: p_50/p_25 should equal p_75/p_50 should equal p_100/p_75
        # With propeller (power ~ speed³ ~ throttle³), ratios should differ
        ratio_1 = p_50 / p_25 if p_25 > 0 else 0
        ratio_2 = p_75 / p_50 if p_50 > 0 else 0
        ratio_3 = p_100 / p_75 if p_75 > 0 else 0
        
        # These ratios should NOT all be equal (non-linear behavior)
        # Note: the exact relationship depends on motor/propeller constants
        # but it should not be a constant 2.0 ratio (linear doubling)
        assert p_25 > 0
        assert p_50 > p_25
        assert p_100 > p_75


class TestPropellerLoadFactor:
    """Test propeller load factor for cruise equilibrium simulation."""
    
    def test_default_load_factor_is_one(self):
        """Default load factor should be 1.0 (startup/bollard)."""
        propeller = PropellerConstants(kp=0.0008)
        assert propeller.load_factor == 1.0
        assert propeller.effective_kp == 0.0008
    
    def test_load_factor_scales_kp(self):
        """Load factor should scale effective_kp."""
        propeller = PropellerConstants(kp=0.0008, load_factor=0.5)
        assert abs(propeller.effective_kp - 0.0004) < 1e-10
    
    def test_load_factor_zero_gives_zero_kp(self):
        """Load factor 0 should give zero effective propeller load."""
        propeller = PropellerConstants(kp=0.0008, load_factor=0.0)
        assert propeller.effective_kp == 0.0
    
    def test_lower_load_factor_reduces_power(self):
        """Lower load factor (cruise) should draw less power than startup."""
        motor = MotorConstants(kv=150, resistance=0.05, no_load_current=1.0)
        
        prop_startup = PropellerConstants(kp=0.0008, load_factor=1.0)
        prop_cruise = PropellerConstants(kp=0.0008, load_factor=0.5)
        
        model_startup = MotorModel(motor, prop_startup, bus_voltage=48.0)
        model_cruise = MotorModel(motor, prop_cruise, bus_voltage=48.0)
        
        op_startup = model_startup.calculate_operating_point(0.75)
        op_cruise = model_cruise.calculate_operating_point(0.75)
        
        assert op_startup.power_electrical_w > op_cruise.power_electrical_w
        assert op_startup.propeller_load_factor == 1.0
        assert op_cruise.propeller_load_factor == 0.5
    
    def test_lower_load_factor_higher_speed(self):
        """Lower load factor should result in higher motor speed."""
        motor = MotorConstants(kv=150, resistance=0.05)
        
        prop_startup = PropellerConstants(kp=0.0008, load_factor=1.0)
        prop_cruise = PropellerConstants(kp=0.0008, load_factor=0.5)
        
        model_startup = MotorModel(motor, prop_startup, bus_voltage=48.0)
        model_cruise = MotorModel(motor, prop_cruise, bus_voltage=48.0)
        
        op_startup = model_startup.calculate_operating_point(0.75)
        op_cruise = model_cruise.calculate_operating_point(0.75)
        
        assert op_cruise.speed_rpm > op_startup.speed_rpm
    
    def test_load_factor_in_operating_point_output(self):
        """Operating point should include the load factor used."""
        motor = MotorConstants(kv=150, resistance=0.05)
        propeller = PropellerConstants(kp=0.0008, load_factor=0.3)
        model = MotorModel(motor, propeller, bus_voltage=48.0)
        
        op = model.calculate_operating_point(0.5)
        assert op.propeller_load_factor == 0.3
    
    def test_zero_throttle_includes_load_factor(self):
        """Zero throttle result should still include load factor."""
        motor = MotorConstants(kv=150, resistance=0.05)
        propeller = PropellerConstants(kp=0.0008, load_factor=0.4)
        model = MotorModel(motor, propeller, bus_voltage=48.0)
        
        op = model.calculate_operating_point(0.0)
        assert op.propeller_load_factor == 0.4
    
    def test_config_factory_reads_load_factor(self):
        """create_motor_model_from_config should read propeller_load_factor."""
        config = {
            "motor_kv": 150,
            "motor_resistance": 0.05,
            "propeller_kp": 0.0008,
            "propeller_load_factor": 0.5
        }
        model = create_motor_model_from_config(config, bus_voltage=48.0)
        
        assert model.propeller.load_factor == 0.5
        assert abs(model.propeller.effective_kp - 0.0004) < 1e-10
    
    def test_config_factory_defaults_load_factor(self):
        """create_motor_model_from_config should default load_factor to 1.0."""
        config = {
            "motor_kv": 150,
            "motor_resistance": 0.05,
            "propeller_kp": 0.0008
        }
        model = create_motor_model_from_config(config, bus_voltage=48.0)
        
        assert model.propeller.load_factor == 1.0


class TestESCCurrentLimiting:
    """Test ESC winding current limiting."""
    
    def test_current_limited_at_high_throttle(self):
        """Motor should be current-limited when demand exceeds max_current."""
        motor = MotorConstants(kv=120, resistance=0.04, no_load_current=2.0)
        propeller = PropellerConstants(kp=0.001)
        model = MotorModel(motor, propeller, bus_voltage=48.0, max_current=83.3)
        
        op = model.calculate_operating_point(1.0)
        
        assert op.current_amps <= 83.3 + 0.01
        assert op.is_current_limited
    
    def test_not_current_limited_at_low_throttle(self):
        """Motor should not be limited at low throttle."""
        motor = MotorConstants(kv=120, resistance=0.04, no_load_current=2.0)
        propeller = PropellerConstants(kp=0.001)
        model = MotorModel(motor, propeller, bus_voltage=48.0, max_current=83.3)
        
        op = model.calculate_operating_point(0.05)
        
        assert not op.is_current_limited
    
    def test_no_limiting_without_max_current(self):
        """Without max_current, current should not be limited."""
        motor = MotorConstants(kv=120, resistance=0.04, no_load_current=2.0)
        propeller = PropellerConstants(kp=0.001)
        model = MotorModel(motor, propeller, bus_voltage=48.0)
        
        op = model.calculate_operating_point(1.0)
        
        assert not op.is_current_limited
    
    def test_stall_current_limited(self):
        """Stall current should also be limited by max_current."""
        motor = MotorConstants(kv=120, resistance=0.04, no_load_current=2.0)
        model = MotorModel(motor, bus_voltage=48.0, max_current=83.3)
        
        # Very low throttle with high propeller load can cause stall
        propeller = PropellerConstants(kp=100.0)  # Extremely heavy propeller
        model_stall = MotorModel(motor, propeller, bus_voltage=48.0, max_current=83.3)
        
        op = model_stall.calculate_operating_point(0.01)
        assert op.current_amps <= 83.3 + 0.01
    
    def test_power_plateaus_when_limited(self):
        """Power should plateau when current is limited."""
        motor = MotorConstants(kv=120, resistance=0.04, no_load_current=2.0)
        propeller = PropellerConstants(kp=0.001)
        model = MotorModel(motor, propeller, bus_voltage=48.0, max_current=83.3)
        
        op_80 = model.calculate_operating_point(0.8)
        op_100 = model.calculate_operating_point(1.0)
        
        if op_80.is_current_limited and op_100.is_current_limited:
            # Power should be the same when both are limited
            assert abs(op_80.power_electrical_w - op_100.power_electrical_w) < 1.0


class TestAutoKpDerivation:
    """Test auto-derivation of propeller kp from motor specs."""
    
    def test_derive_kp_reaches_rated_current(self):
        """Auto-derived kp should make motor reach rated current at full throttle."""
        config = {
            'motor_kv': 120,
            'motor_resistance': 0.04,
            'motor_no_load_current': 2.0,
            'total_power': 4000,
            'nominal_voltage': 48.0
        }
        model = create_motor_model_from_config(config, bus_voltage=48.0)
        
        assert model is not None
        assert model.propeller is not None
        assert model.max_current is not None
        
        op = model.calculate_operating_point(1.0)
        
        # At full throttle, current should be very close to max_current
        expected_max = 4000 / 48.0  # 83.333A
        assert abs(op.current_amps - expected_max) < 0.5
    
    def test_explicit_kp_overrides_auto(self):
        """Explicit propeller_kp should override auto-derivation."""
        config = {
            'motor_kv': 120,
            'motor_resistance': 0.04,
            'motor_no_load_current': 2.0,
            'propeller_kp': 0.005,
            'total_power': 4000,
            'nominal_voltage': 48.0
        }
        model = create_motor_model_from_config(config, bus_voltage=48.0)
        
        assert model.propeller.kp == 0.005
    
    def test_auto_kp_without_power_specs(self):
        """Without total_power/nominal_voltage, no propeller coupling."""
        config = {
            'motor_kv': 120,
            'motor_resistance': 0.04
        }
        model = create_motor_model_from_config(config, bus_voltage=48.0)
        
        assert model.propeller is None
        assert model.max_current is None
    
    def test_derive_kp_function_positive(self):
        """derive_propeller_kp should return a positive value."""
        kp = derive_propeller_kp(
            kv=120, resistance=0.04, no_load_current=2.0,
            total_power=4000, nominal_voltage=48.0
        )
        assert kp > 0
    
    def test_full_throttle_not_limited_before_1(self):
        """Motor should not be current-limited at throttle < ~0.95."""
        config = {
            'motor_kv': 120,
            'motor_resistance': 0.04,
            'motor_no_load_current': 2.0,
            'total_power': 4000,
            'nominal_voltage': 48.0
        }
        model = create_motor_model_from_config(config, bus_voltage=48.0)
        
        op_50 = model.calculate_operating_point(0.5)
        assert not op_50.is_current_limited
    
    def test_power_increases_across_throttle_range(self):
        """Power should increase across the full throttle range with auto-kp."""
        config = {
            'motor_kv': 120,
            'motor_resistance': 0.04,
            'motor_no_load_current': 2.0,
            'total_power': 4000,
            'nominal_voltage': 48.0
        }
        model = create_motor_model_from_config(config, bus_voltage=48.0)
        
        p_25 = model.get_power_from_throttle(0.25)
        p_50 = model.get_power_from_throttle(0.50)
        p_75 = model.get_power_from_throttle(0.75)
        p_100 = model.get_power_from_throttle(1.0)
        
        assert p_25 < p_50 < p_75 <= p_100


class TestNoLoadCurrentFix:
    """Test that no-load current is not double-counted."""
    
    def test_current_at_no_load_speed(self):
        """At near no-load speed, current should be close to no-load current."""
        motor = MotorConstants(kv=150, resistance=0.05, no_load_current=1.5)
        # Very light propeller so motor runs near no-load speed
        propeller = PropellerConstants(kp=1e-7)
        model = MotorModel(motor, propeller, bus_voltage=48.0)
        
        op = model.calculate_operating_point(0.5)
        
        # Current should be near no-load current, not 2x
        assert op.current_amps < motor.no_load_current * 3
    
    def test_torque_uses_net_current(self):
        """Torque should use (I - I_nl), not raw I."""
        motor = MotorConstants(kv=150, resistance=0.05, no_load_current=1.5)
        propeller = PropellerConstants(kp=0.0001)
        model = MotorModel(motor, propeller, bus_voltage=48.0)
        
        op = model.calculate_operating_point(0.5)
        
        expected_torque = motor.kt * max(0, op.current_amps - motor.no_load_current)
        assert abs(op.torque_nm - expected_torque) < 0.01


if __name__ == "__main__":
    pytest.main([__file__, "-v"])

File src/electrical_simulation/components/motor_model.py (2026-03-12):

"""
BLDC Motor Physics Model with Optional Propeller Load Coupling

This module calculates realistic power consumption from throttle input by solving
the motor-propeller equilibrium equations. The model accounts for:
- Back-EMF (speed-dependent voltage opposing current)
- Winding resistance losses
- No-load current (friction, windage)
- Propeller load curve (torque ∝ ω²)

Motor Equations:
    V_effective = throttle x V_bus
    V_emf = Ke x ω (back-EMF)
    I = (V_effective - V_emf) / R_winding
    τ_motor = Kt x (I - I_no_load)
    V_motor = Ke x ω + I x R  (actual terminal voltage)
    P_electrical = V_motor x I

Propeller Equilibrium:
    τ_propeller = Kp x ω²
    At equilibrium: τ_motor = τ_propeller
"""

import math
from dataclasses import dataclass
from typing import Optional, Tuple


@dataclass
class MotorConstants:
    """BLDC motor electrical and mechanical constants."""
    kv: float  # Motor velocity constant (RPM/V)
    resistance: float  # Winding resistance (ohms)
    no_load_current: float = 0.0  # No-load current (amps)
    
    @property
    def ke(self) -> float:
        """Back-EMF constant (V/(rad/s)), derived from Kv."""
        return 60.0 / (2.0 * math.pi * self.kv)
    
    @property
    def kt(self) -> float:
        """Torque constant (N·m/A), equals Ke for BLDC motors."""
        return self.ke


@dataclass
class PropellerConstants:
    """Propeller load curve constants."""
    kp: float  # Load coefficient (N·m/(rad/s)²)
    load_factor: float = 1.0  # 1.0 = startup/bollard, <1.0 = cruise equilibrium
    
    @property
    def effective_kp(self) -> float:
        """Kp scaled by load_factor to model reduced load at cruise speed."""
        return self.kp * self.load_factor


@dataclass
class MotorOperatingPoint:
    """Results from motor equilibrium calculation."""
    throttle: float  # Input throttle [0, 1]
    speed_rpm: float  # Motor speed (RPM)
    speed_rad_s: float  # Motor speed (rad/s)
    current_amps: float  # Motor current draw (A)
    torque_nm: float  # Motor torque (N·m)
    power_electrical_w: float  # Electrical power consumption (W)
    power_mechanical_w: float  # Mechanical power output (W)
    efficiency: float  # Motor efficiency (0-1)
    is_stalled: bool  # True if motor is in stall condition
    is_current_limited: bool = False  # True if ESC is limiting winding current
    propeller_load_factor: float = 1.0  # Load factor used (1.0=startup, <1.0=cruise)
    

class MotorModel:
    """
    BLDC motor model with optional propeller load coupling.
    
    Calculates power consumption from throttle by solving for the equilibrium
    operating point where motor torque equals propeller load torque.
    """
    
    SPEED_TOLERANCE = 1e-6  # rad/s convergence tolerance
    MAX_ITERATIONS = 100
    MIN_SPEED_RAD_S = 0.01  # Minimum speed to avoid division by zero
    
    def __init__(
        self,
        motor: MotorConstants,
        propeller: Optional[PropellerConstants] = None,
        bus_voltage: float = 48.0,
        max_power: float = None,
        max_current: float = None
    ):
        """
        Initialize motor model.
        
        Args:
            motor: Motor electrical constants
            propeller: Propeller load constants (optional)
            bus_voltage: DC bus voltage (V)
            max_power: Maximum power rating for fallback linear model (W)
            max_current: ESC winding current limit (A), typically total_power/nominal_voltage
        """
        self.motor = motor
        self.propeller = propeller
        self.bus_voltage = bus_voltage
        self.max_power = max_power
        self.max_current = max_current
        
    def calculate_operating_point(self, throttle: float) -> MotorOperatingPoint:
        """
        Calculate motor operating point for given throttle.
        
        For propeller-coupled motors, solves equilibrium equation.
        For uncoupled motors, uses simplified model.
        
        Args:
            throttle: Throttle position [0, 1]
            
        Returns:
            MotorOperatingPoint with all calculated values
        """
        if throttle <= 0.0:
            return self._zero_throttle_result()
        
        throttle = min(throttle, 1.0)  # Clamp to valid range
        
        if self.propeller:
            return self._solve_propeller_equilibrium(throttle)
        else:
            return self._solve_simple_model(throttle)
    
    def _zero_throttle_result(self) -> MotorOperatingPoint:
        """Return operating point for zero throttle."""
        load_factor = self.propeller.load_factor if self.propeller else 1.0
        return MotorOperatingPoint(
            throttle=0.0,
            speed_rpm=0.0,
            speed_rad_s=0.0,
            current_amps=0.0,
            torque_nm=0.0,
            power_electrical_w=0.0,
            power_mechanical_w=0.0,
            efficiency=0.0,
            is_stalled=False,
            propeller_load_factor=load_factor
        )
    
    def _solve_propeller_equilibrium(self, throttle: float) -> MotorOperatingPoint:
        """
        Solve for equilibrium speed where motor torque = propeller torque.
        
        Motor torque: τ_m = Kt x (I - I_nl)
        Motor current: I = (V_eff - Kexω) / R
        Propeller torque: τ_p = Kp x ω²
        
        At equilibrium: Kt x ((V_eff - Kexω)/R - I_nl) = Kp x ω²
        
        Rearranging: Kpxω² + (KtxKe/R)xω + KtxI_nl - KtxV_eff/R = 0
        
        This is a quadratic in ω, but we use Newton-Raphson for robustness.
        """
        v_effective = throttle * self.bus_voltage
        kt = self.motor.kt
        ke = self.motor.ke
        r = self.motor.resistance
        i_nl = self.motor.no_load_current
        kp = self.propeller.effective_kp
        
        # Initial guess: no-load speed (back-EMF equals applied voltage)
        omega_no_load = v_effective / ke if ke > 0 else 0
        omega = omega_no_load * 0.8  # Start slightly below no-load
        
        # Phase 1: Solve unconstrained equilibrium via Newton-Raphson
        for _ in range(self.MAX_ITERATIONS):
            i_motor = (v_effective - ke * omega) / r
            
            if i_motor < i_nl:
                return self._stall_result(throttle, v_effective)
            
            tau_motor = kt * (i_motor - i_nl)
            tau_prop = kp * omega * omega
            f = tau_motor - tau_prop
            
            # d(tau_motor)/d(omega) = -Kt x Ke / R
            # d(tau_prop)/d(omega) = 2 x Kp x omega
            df = -kt * ke / r - 2 * kp * omega
            
            if abs(df) < 1e-12:
                break
                
            omega_new = omega - f / df
            omega_new = max(self.MIN_SPEED_RAD_S, min(omega_new, omega_no_load))
            
            if abs(omega_new - omega) < self.SPEED_TOLERANCE:
                omega = omega_new
                break
                
            omega = omega_new
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

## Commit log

2025-12-27 Add executable permission to fix_visibility.sh
    [RotiProa2.FCStd]
2026-01-04 editing landing page
2026-01-16 Rename entry point scripts to __main__.py and use python -m
    - Rename all main scripts to __main__.py for Pythonic module execution
    - Update Makefile to use python -m src.module where possible
    - Add src/step/__init__.py (was missing)
    - FreeCAD design stage still uses file path (FreeCAD requirement)
2026-01-30 tiller rod added
2026-02-02 indo version updated
    [rp2.beaching.step.step]
2026-02-15 Fix CI: install shipshape into FreeCAD's bundled Python
    Mass, buoyancy, and gz stages run under FreeCAD's Python
    (squashfs-root/usr/bin/python) which doesn't see system pip packages.
2026-02-16 manual merge of cables PR, due to too many merge conflicts
2026-03-02 Hide import warnings for pyside
    Warning is caused by lack of local library in device as the library used
    is from wsl
2026-03-07 Added extra note on electrical schematics
2026-03-07 Update schematics from svg to png
2026-03-11 Extend motor physics
    Accounted for basic back emf and water resistance in water.
    Implemented with Copilot:
    copilot --resume=8dd7bec8-42b2-4533-a7ae-539164240ff3
    Will review and update the generated code to fix output json files and motor model
    [load.py, motor_model.py, result_checker.py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]
2026-03-12 fixed esc missing current limit
    Issue causes motor to draw max current at low throttle
    [load.py, motor_model.py, result_checker.py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]
2026-09-01 Add Windows support for build tooling and FreeCAD headless GUI init
    Makefile now detects Windows via $(OS), wires up Git Bash as SHELL,
    adds Git's usr/bin coreutils to PATH, forces PYTHONUTF8 for unicode
    console output, and points PYTHON/FREECAD at FreeCAD's bundled
    python.exe and freecadcmd.exe since there's normally no separate
    Python install on Windows.
    freecadcmd has no Qt event loop on Windows just like on Linux, so
    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
2026-09-07 Add ISO 12215 structural traceability for RP2
    Cross-checks RP2's existing structural safety factors against the BS EN
    ISO 12215 small-craft standard series, resolving the monohull-vs-proa gap
    by confirming ISO 12215-7:2020 (multihull loads) is on file and applying
    it to the aka/crossbeam system alongside ISO 12215-3/5/6/10.
    - Fix mast wind-force formula: an erroneous extra /2 (not present in the
    ISO 12215-10:2020 source, Table 5 Note 3) halved the applied wind force,
    moving the reported safety factor from 6.18 to the correct 3.09.
    - Add iso_materials.py: ISO 12215-3 4.7 aluminium alloy family check and
    material documentation traceability (data sheet not yet finalized).
    - Add iso_joint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
2026-09-13 Address PR #13 review: sync mast doc, resolve joint/material check gaps
    - docs/validation_rp2.md: correct the mast wind-force formula and its
    rationale, which still showed the pre-fix formula with a fabricated
    explanation ("load shared between two masts") after mast_analysis.py's
    /2 bug was fixed - it now matches iso_traceability.md.
    - iso_joint_check.py: get_aka_peak_load() now compares the static
    suspended-ama demand against the ISO 12215-7 GLC5 dynamic demand and
    uses the governing (larger) moment/shear for the weld sizing check,
    instead of only ever checking the static case the docstring itself
    said GLC5 could exceed.
    - iso_materials.py: check_alloy_family_consistency() has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
